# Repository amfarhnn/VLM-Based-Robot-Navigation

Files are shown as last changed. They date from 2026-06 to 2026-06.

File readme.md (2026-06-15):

<p align="center">
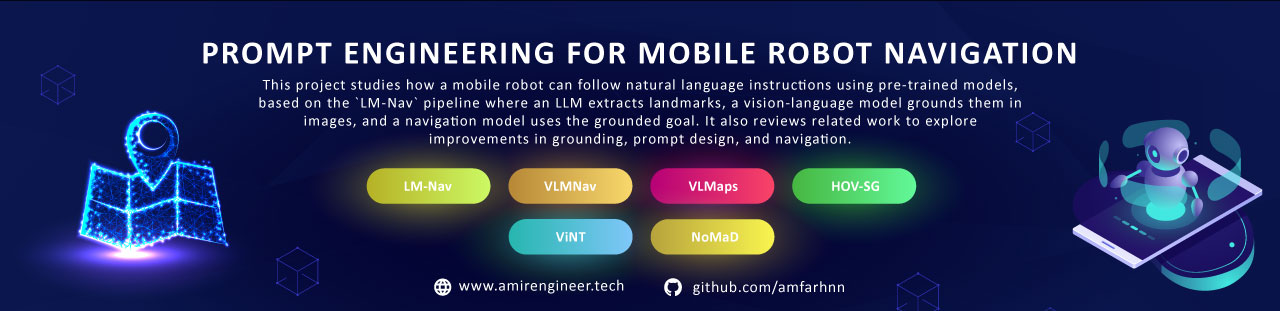
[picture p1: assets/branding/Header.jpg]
Prompt Engineering for Mobile Robot Navigation
  
</p>

# Prompt Engineering for Mobile Robot Navigation

<p align="center">
  A low-cost Raspberry Pi 4 and ESP32 mobile robot that converts a simple
  natural-language goal into restricted, safety-checked movement actions.
</p>

<p align="center">
  
  
  
  
  
</p>

## Final Thesis

The final FYP1 thesis, covering Chapters 1 to 5, is available here:

- [2115617_2_AmirFarhanGhaffar.pdf.docx](2115617_2_AmirFarhanGhaffar.pdf.docx)

The thesis is the source of truth for the finalized project scope, methodology,
AI-model research plan, Docker results, limitations, and planned FYP2 work.

## Prototype

<p align="center">
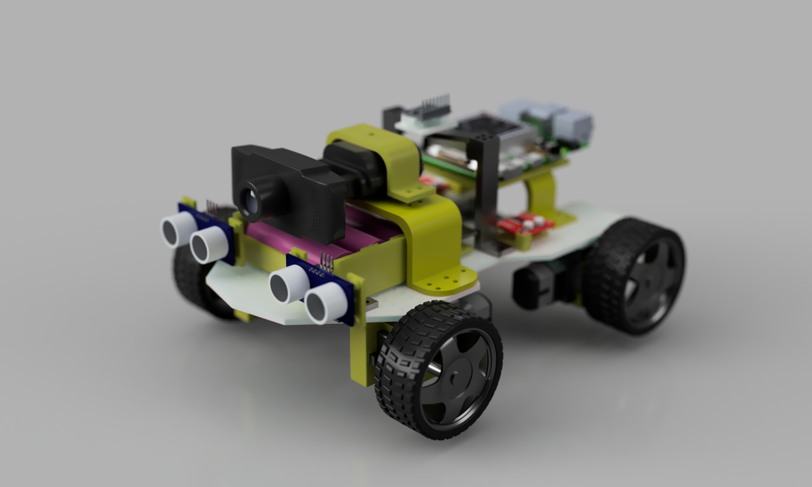
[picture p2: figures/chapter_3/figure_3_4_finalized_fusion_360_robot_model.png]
Finalized Fusion 360 Raspberry Pi robot model
  
</p>

The physical prototype uses:

- Raspberry Pi 4 for prompt processing, webcam perception, action selection,
  validation, and logging
- ESP32 for ultrasonic sensing, local safety, USB serial, and motor control
- USB webcam, two HC-SR04 sensors, and GY-291/ADXL345 accelerometer
- two MX1508 drivers and four DC gear motors
- protected 3S battery system, regulated power rails, main switch, and fuse

The GY-291/ADXL345 supports acceleration, roll/pitch, motion, vibration, and
shock observations. It does not provide yaw heading.

## Navigation Pipeline

```text
Natural-language instruction
        |
        v
Structured goal and approved action set
        |
        v
USB-webcam visual grounding
        |
        v
Restricted action selection
        |
        v
ESP32 safety validation and motor control
```

Approved actions:

```text
search | turn_left | turn_right | move_forward | stop
```

The ESP32 independently forces `STOP` for obstacles, sensor faults, invalid
commands, or a command timeout.

## Current Results

The completed Docker laptop demonstration accepts:

```text
find the door
```

It uses a fixed-schema prompt result and an OpenCV colour-and-shape detector
tuned to the grey-blue corridor doors used in the test area.

<p align="center">
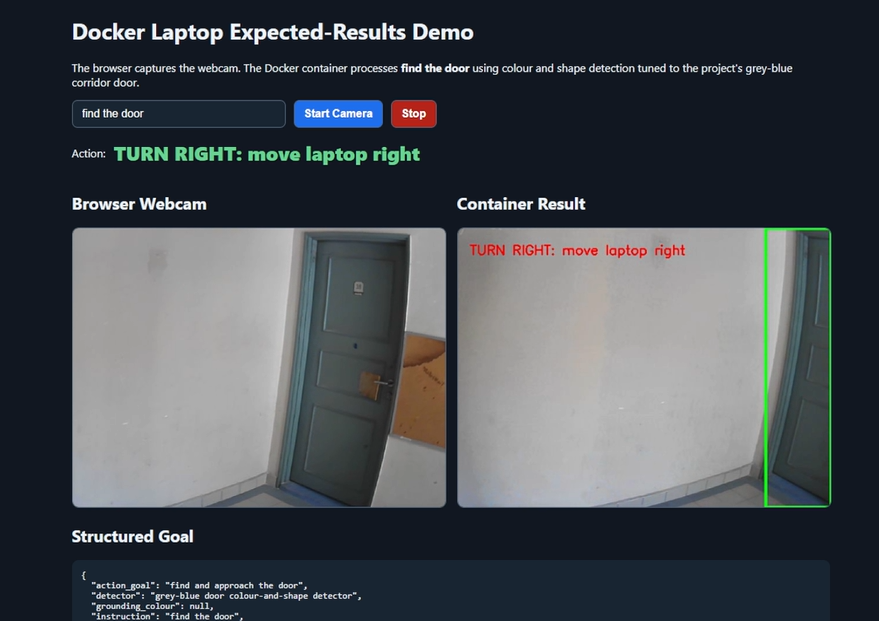
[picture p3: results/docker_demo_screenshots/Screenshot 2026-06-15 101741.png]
Docker demonstration selecting TURN RIGHT for a door on the right
  
</p>

Observed screenshot evidence demonstrates:

| Observed condition | Displayed action |
|---|---|
| No valid door region | `SEARCH` |
| Door detected on the right | `TURN RIGHT` |
| Door reaches the configured apparent-size threshold | `STOP` |

The Docker demonstration validates the high-level software interface. The
laptop was moved manually, and these results are not physical robot movement.

## AI Research Plan

The implemented deterministic parser, OpenCV detector, and rule-based action
selector form the measurable baseline. The thesis proposes three AI candidates
for later comparison:

| Candidate | Research role |
|---|---|
| Quantized TinyLlama | Convert instructions into the fixed navigation schema |
| MobileNetV2-SSD Lite TensorFlow Lite | Lightweight custom indoor-object grounding |
| VLM-NAV-inspired neural classifier | Compare learned and rule-based action selection |

Model output must pass deterministic validation and cannot bypass ESP32 safety.

## Project Status

| Area | Status |
|---|---|
| Final FYP1 thesis, Chapters 1-5 | Complete |
| Fusion 360 design and printable mounts | Complete |
| Mechanical chassis and protected power system | Built |
| Docker `find the door` demonstration | Working |
| Raspberry Pi controller and ESP32 firmware | Implemented |
| Final Raspberry Pi, ESP32, sensor, and motor wiring | In progress |
| Raised-wheel and controlled-floor validation | Planned for FYP2 |
| AI-model comparison and physical navigation measurements | Planned for FYP2 |

## Quick Start: Docker Demo

Requirements:

- Docker Desktop using Linux containers
- browser webcam permission
- local port `8000`

Run from the repository root:

```powershell
docker compose -f docker-compose.laptop-demo.yml up --build
```

Open <http://localhost:8000>, select **Start Camera**, and enter
`find the door`.

Stop the demonstration:

```powershell
docker compose -f docker-compose.laptop-demo.yml down
```

Full instructions:
[Docker Laptop Demonstration Setup](docs/laptop_only_expected_results_setup.md)

## Physical Robot Setup

1. Complete the signal wiring using the
   [Raspberry Pi, ESP32, and MX1508 Wiring Guide](docs/circuit_wiring_guide.md).
2. Flash
   [`firmware/esp32_robot_controller/esp32_robot_controller.ino`](firmware/esp32_robot_controller/esp32_robot_controller.ino).
3. Install Raspberry Pi OS and dependencies using the
   [Raspberry Pi 4 Full Software Setup](docs/raspberry_pi_4_full_software_setup.md).
4. Run the Raspberry Pi controller without `--execute` for the first dry test.
5. Enable movement only during supervised raised-wheel testing.

Example dry run:

```bash
python3 src/raspberry_pi_robot/robot_controller.py \
  --instruction "find the green marker" \
  --camera 0 \
  --serial-device /dev/ttyUSB0
```

The controller always sends `STOP` unless `--execute` is explicitly provided.

## Safety

- Never power motors from Raspberry Pi or ESP32 logic pins.
- Level-shift both 5 V HC-SR04 Echo signals before ESP32 GPIO.
- Keep a common ground between the battery system, power modules, ESP32,
  sensors, and motor drivers.
- Begin motor tests with all wheels raised and the main switch reachable.
- Verify `STOP`, obstacle, sensor-fault, invalid-command, and timeout behaviour
  before any controlled-floor test.

## Repository Structure

| Path | Purpose |
|---|---|
| [`2115617_2_AmirFarhanGhaffar.pdf.docx`](2115617_2_AmirFarhanGhaffar.pdf.docx) | Final FYP1 thesis, Chapters 1-5 |
| [`src/raspberry_pi_robot/`](src/raspberry_pi_robot/) | Raspberry Pi prompt, camera, action, serial, and logging controller |
| [`src/laptop_expected_results/`](src/laptop_expected_results/) | Docker browser-webcam demonstration |
| [`firmware/`](firmware/) | Main ESP32 controller and sensor-only test firmware |
| [`docs/`](docs/) | Wiring, setup, method-selection, and presentation guides |
| [`results/docker_demo_screenshots/`](results/docker_demo_screenshots/) | Captured Docker result screenshots |
| [`simulations/`](simulations/) | Assumption-based obstacle and timeout safety simulations |
| [`figures/`](figures/) | Final report and public-view figures |
| [`drawio/`](drawio/) | Editable and exported report diagrams |
| [`cad/design_sources/`](cad/design_sources/) | Fusion 360 renders, drawing, and design source |
| [`cad/stl/`](cad/stl/) | Printable robot mounts |
| [`assets/`](assets/) | README branding and hardware-component image sources |
| [`scripts/`](scripts/) | Reproducible figure-generation utilities |
| [`github-research-papers/`](github-research-papers/) | Related research implementations used for method study |

## Supporting Documentation

- [FYP1 15-Minute Presentation Script](docs/fyp1_15_minute_presentation_script.md)
- [Research-Paper Method Selection](docs/research_paper_method_selection.md)
- [Docker Laptop Demonstration Setup](docs/laptop_only_expected_results_setup.md)
- [Raspberry Pi 4 Full Software Setup](docs/raspberry_pi_4_full_software_setup.md)
- [Circuit Wiring Guide](docs/circuit_wiring_guide.md)

## Limitations

- The Docker detector is tuned to grey-blue doors in one corridor and is not a
  general semantic door-recognition model.
- Door stopping uses apparent image area, not measured physical distance.
- Two ultrasonic sensors provide limited obstacle coverage.
- The first physical baseline uses coloured-marker grounding.
- Complete physical action validation and AI-model comparison remain FYP2 work.

## Author

**Amir Farhan Bin Ghaffar**<br>
Final Year Project, Department of Mechatronics Engineering<br>
International Islamic University Malaysia

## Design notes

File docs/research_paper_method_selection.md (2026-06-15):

# Research-Paper Method Selection for the Raspberry Pi Robot

## 1. Purpose

This document evaluates the repositories in `github-research-papers` against
the finalized project hardware:

- Raspberry Pi 4 with one USB RGB webcam
- ESP32 with two front HC-SR04 ultrasonic sensors
- GY-291 / ADXL345 accelerometer
- two MX1508 motor drivers and four DC gear motors
- USB serial communication between Raspberry Pi and ESP32

The current robot has no RGB-D camera, wheel encoders, reliable yaw sensor,
LiDAR, GPS, SLAM pose, ROS installation, or GPU accelerator. Therefore, the
best approach is to adapt selected research methods rather than attempt to run
one complete research repository.

## 2. Recommended Combined Method

The most suitable design combines ideas from four repositories:

1. **LM-Nav:** convert a language instruction into an ordered list of
   landmarks or targets.
2. **VLM-NAV:** use a small discrete action space and fuse perception,
   obstacle sensing, and previous-action information.
3. **NaVid / NaVILA:** use recent visual history and separate high-level
   decisions from the real-time safety controller.
4. **ViNT:** optionally add a simple taught-route image sequence in future
   work.

The resulting project-specific pipeline is:

```text
Natural-language instruction
        |
        v
Constrained landmark and goal extraction
        |
        v
Recent webcam frames + marker or object grounding
        |
        v
Rule-based or lightweight learned action selector
        |
        v
Restricted action: search / left / right / forward / stop
        |
        v
ESP32 obstacle, sensor-fault, invalid-command, and timeout safety
        |
        v
MX1508 motor drivers and four motors
```

## 3. Compatibility Summary

| Repository | Suitable Part | Suitability | Main Limitation |
|---|---|---:|---|
| `lm_nav` | Ordered landmark extraction and modular pipeline | High | Full graph routing requires localization and visual embeddings |
| `vlm_nav` | Discrete actions, sensor fusion, previous-action memory, tiny action network | High with adaptation | Original method assumes depth maps, heading, AirSim, and optional API VLM |
| `NaVILA` | Two-level high-level decision and low-level safety concept | High as an architecture principle | Full VLA model requires powerful GPU hardware |
| `NaVid-VLN-CE` | Recent-frame history and constrained action parsing | Medium as a lightweight adaptation | Full video VLM requires GPU and simulator stack |
| `visualnav-transformer` | Taught-route image keyframes and waypoint-control concept | Medium for future work | Full ViNT/NoMaD deployment expects ROS, odometry, and stronger compute |
| `vlmaps` | Language-indexed map and spatial instruction ideas | Low for current hardware | Requires RGB-D frames and reliable camera or robot poses |
| `HOV-SG` | Floor-room-object hierarchy for future prompt design | Low for current hardware | Requires posed RGB-D, large models, point clouds, and substantial RAM/GPU |

## 4. Methods Suitable for the Current Prototype

### 4.1 LM-Nav Ordered Landmark Extraction

LM-Nav separates instruction interpretation from visual navigation. Its
landmark-extraction stage converts a full instruction into an ordered landmark
list.

Relevant local files:

- `github-research-papers/lm_nav/lm_nav/landmark_extraction.py`
- `github-research-papers/lm_nav/lm_nav/pipeline.py`

This method fits the project title and can extend the current fixed-schema
parser without requiring a large onboard model.

Example:

```text
Instruction: Find the green marker, then find the blue marker.

Structured goal:
{
  "ordered_targets": ["green marker", "blue marker"],
  "current_target_index": 0,
  "allowed_actions": ["search", "turn_left", "turn_right", "move_forward", "stop"]
}
```

For the first prototype, keep one supported target. Ordered multi-target
navigation should only be enabled after single-target trials are reliable.

### 4.2 VLM-NAV Discrete Action and Sensor-Fusion Method

VLM-NAV uses three discrete movement actions and combines perception with
left/right distance sensing, previous action, and rule-based decisions.

Relevant local files:

- `github-research-papers/vlm_nav/vlm_nav/vlm_navigation.py`
- `github-research-papers/vlm_nav/vlm_nav/navigator.py`
- `github-research-papers/vlm_nav/vlm_nav/navigation_learner.py`

The current project already uses a compatible restricted action set. The
method can be adapted using available robot observations:

| Research Input | Project Adaptation |
|---|---|
| Depth-map regions | Marker or object visibility, centre position, and area |
| Left/right distance sensors | Front-left and front-right HC-SR04 distance |
| Relative heading | Not available; do not claim yaw from the ADXL345 |
| Previous action | Store the previous selected action |
| Three movement actions | Use left, right, and forward plus safe search and stop |

Previous-action memory is useful for reducing rapid left-right oscillation.
However, the research code sometimes resolves an opposite turn by forcing
forward movement. The physical robot must instead keep the safer turn or stop;
it must never move forward only to suppress oscillation.

### 4.3 Tiny Learned Action Selector

The VLM-NAV `Navigator` is a small fully connected network. A similarly small
classifier can run on Raspberry Pi CPU after enough robot-specific data has
been collected.

Recommended future input features:

```text
target_visible
target_center_x
target_area_ratio
front_left_cm
front_right_cm
obstacle
sensor_fault
previous_action
roll_deg
pitch_deg
motion_detected
```

Recommended output classes:

```text
search, turn_left, turn_right, move_forward, stop
```

The rule-based controller should remain the FYP1 baseline. In FYP2, manually
label safe actions, train the small model on a laptop, deploy inference on the
Raspberry Pi, and compare it against the baseline. The ESP32 safety layer must
override either method.

### 4.4 NaVILA Two-Level Control Architecture

NaVILA separates high-level language-based decisions from real-time locomotion
and obstacle avoidance.

Relevant local reference:

- `github-research-papers/NaVILA/README.md`

This principle already matches the project:

| NaVILA Concept | Project Implementation |
|---|---|
| High-level navigation command | Raspberry Pi prompt, vision, and action selection |
| Real-time locomotion and avoidance | ESP32 motor control and deterministic safety |

Use this architecture as research justification. Do not attempt to run the
full NaVILA model on Raspberry Pi 4.

### 4.5 NaVid Recent-Frame History

NaVid uses historical observations and the current image when selecting the
next action.

Relevant local files:

- `github-research-papers/NaVid-VLN-CE/agent_navid.py`
- `github-research-papers/NaVILA/llava/eval/run_navigation.py`

A lightweight version is suitable for Raspberry Pi:

1. Keep the last three to five marker detections, not full VLM features.
2. Use median target centre and area across valid detections.
3. Require repeated evidence before changing turn direction.
4. Stop if the visual history is inconsistent or sensor status is unavailable.

Do not copy NaVid's random-action fallback when model output is invalid. An
invalid decision on the physical robot must produce `stop`.

## 5. Methods Suitable Only for Later Work

### 5.1 ViNT Taught-Route Image Sequence

ViNT creates a topological map from images sampled along a demonstrated route.
The idea can become a future "teach and repeat" mode:

1. Manually drive the robot through a short indoor route.
2. Store ordered webcam keyframes.
3. Match the current image against nearby keyframes.
4. Move toward the next keyframe while ESP32 safety remains active.

For the current hardware, begin with lightweight ORB image matching rather
than the full ViNT/NoMaD neural model. Reliable metric waypoint control would
require wheel encoders and a real heading sensor.

Relevant local files:

- `github-research-papers/visualnav-transformer/deployment/src/create_topomap.py`
- `github-research-papers/visualnav-transformer/deployment/src/pd_controller.py`

### 5.2 VLMaps Spatial Language Ideas

VLMaps demonstrates object-goal and relation-aware instructions such as moving
beside or between objects. These ideas are useful for future prompt schemas,
but its actual mapping pipeline is not compatible with the present robot.

The full method requires RGB-D observations and reliable world-frame poses.
The current USB RGB webcam, ultrasonic sensors, and ADXL345 cannot provide
those inputs.

### 5.3 HOV-SG Hierarchical Scene Representation

The floor-room-object hierarchy is useful as a future language representation:

```text
floor -> room -> object -> action
```

The full HOV-SG implementation is unsuitable for Raspberry Pi 4 because it
uses posed RGB-D data, point clouds, OpenCLIP, SAM, and substantial RAM/GPU
resources.

## 6. Methods Not Recommended for This Setup

Do not use the following as the first physical implementation:

- full NaVILA, NaVid, or Uni-NaVid inference on Raspberry Pi 4
- full VLMaps or HOV-SG map construction
- full ViNT/NoMaD deployment without ROS, odometry, and stronger compute
- monocular estimated depth as the only collision-safety source
- ADXL345 roll or pitch as robot yaw or compass heading
- random movement when parsing, perception, or model output fails
- unrestricted VLM output sent directly to the ESP32

An API-based VLM can be tested as an optional comparison, but network latency,
availability, cost, and unpredictable text output make it unsuitable as the
only physical control method.

## 7. Recommended Implementation Roadmap

### FYP1: Current Basic Prototype

1. Keep the fixed-schema parser and one target: `find the green marker`.
2. Keep OpenCV marker grounding and the restricted five-action set.
3. Add previous-action logging and lightweight temporal detection history.
4. Keep all obstacle and communication safety on the ESP32.
5. Measure prompt validity, grounding correctness, action correctness,
   latency, safe-stop rate, and goal completion.

### FYP2: First Research Extension

1. Extend the parser to ordered supported landmarks.
2. Collect robot-specific observation and safe-action examples.
3. Train a tiny action classifier and compare it with the rule-based baseline.
4. Replace markers with lightweight indoor-object detection.
5. Add a short taught-route image sequence if time permits.

### Hardware Needed Before Map-Based Navigation

- wheel encoders for distance and odometry
- a gyroscope or magnetometer-capable IMU for turning or heading feedback
- preferably an RGB-D camera or LiDAR for map construction
- stronger compute or offboard GPU for large VLM, VLMaps, HOV-SG, or ViNT

## 8. Final Selection

The recommended method for this project is:

> A modular LM-Nav-inspired prompt and landmark pipeline, using a VLM-NAV-style
> restricted action selector with lightweight temporal history, while the
> Raspberry Pi performs high-level decisions and the ESP32 independently
> enforces real-time safety.

This selection is technically realistic for Raspberry Pi 4, directly supports
the project title, and leaves a clear comparison path between rule-based and
small learned action selection for FYP2.

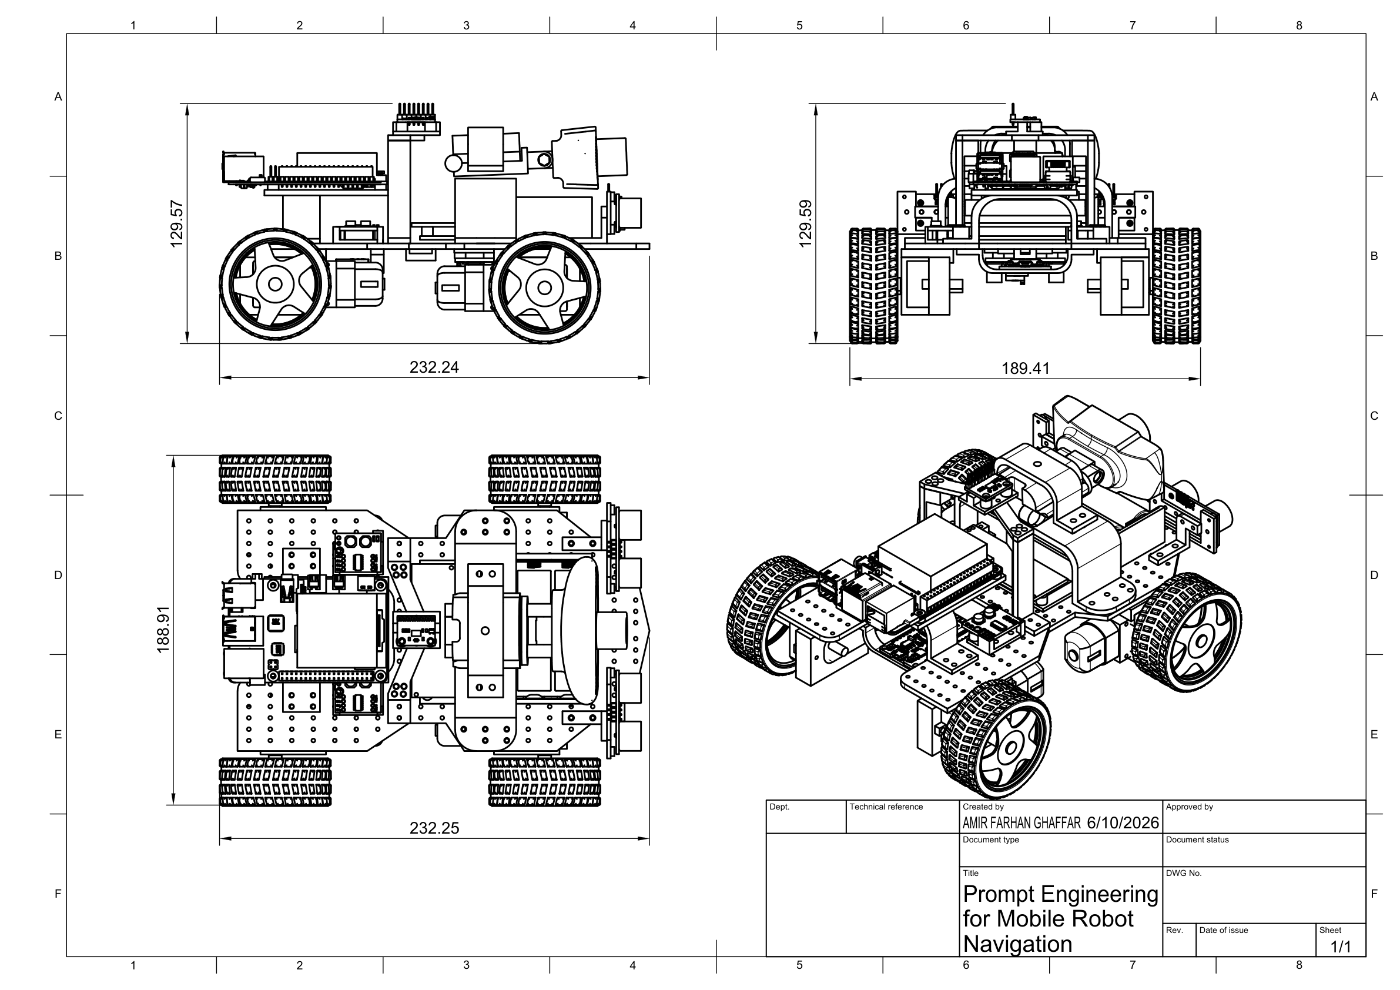
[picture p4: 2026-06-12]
figures/chapter_3/figure_3_6_mechanical_design_sketch_and_dimensions.png

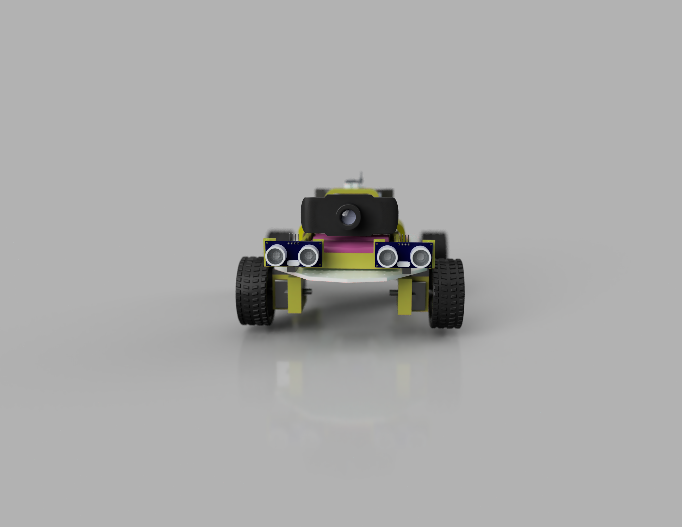
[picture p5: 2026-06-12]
cad/design_sources/FYP_2_2026-Jun-10_09-45-14PM-000_CustomizedView45560590010.png

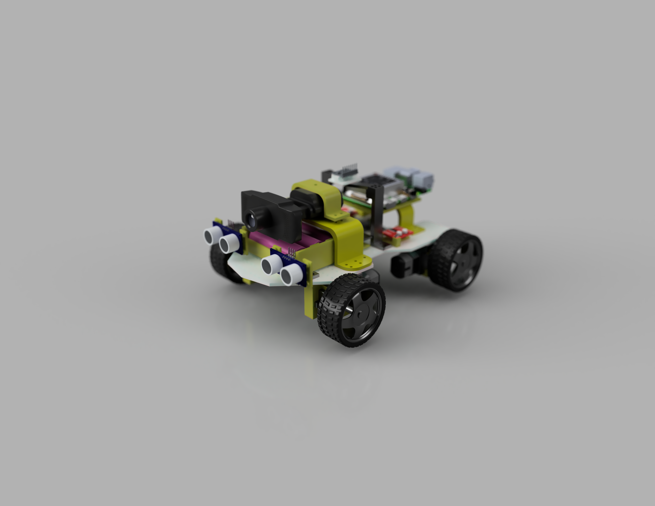
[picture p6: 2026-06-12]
cad/design_sources/FYP_2_2026-Jun-10_09-44-41PM-000_CustomizedView7494680794.png

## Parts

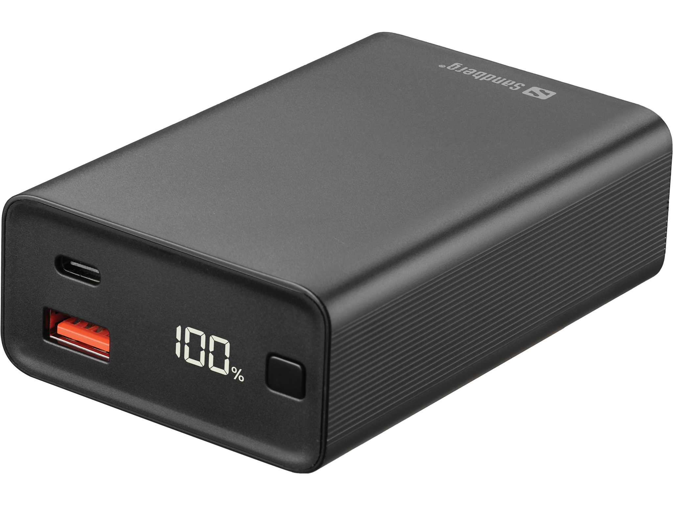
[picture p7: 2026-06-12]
assets/hardware_components/powerbank_battery.jpg

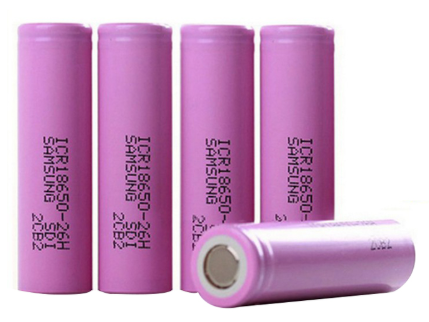
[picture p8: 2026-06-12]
assets/hardware_components/18650_battery.png

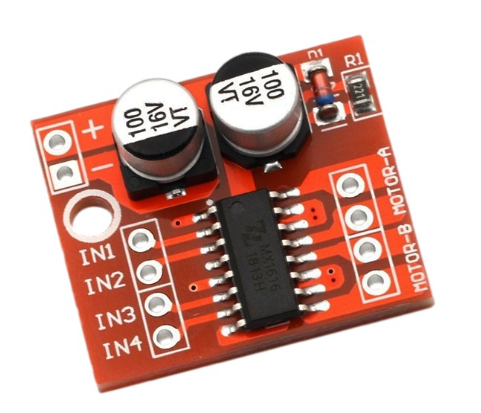
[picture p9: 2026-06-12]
assets/hardware_components/mx1508_motor_driver.png

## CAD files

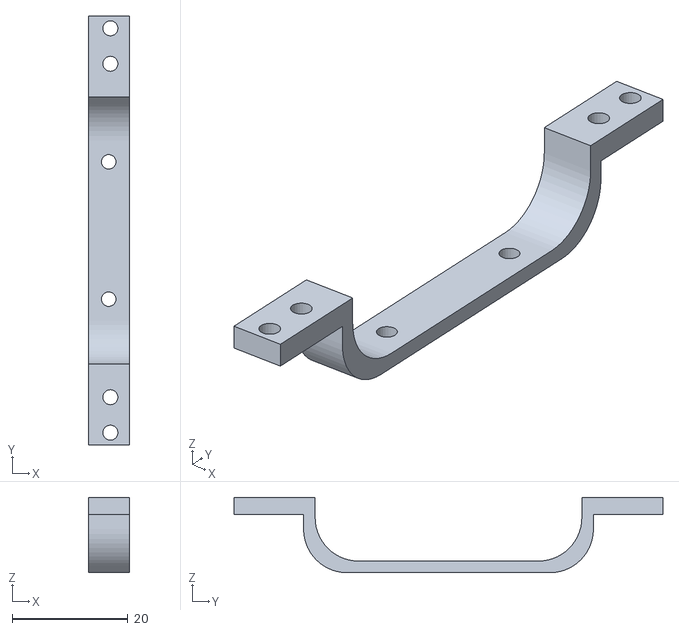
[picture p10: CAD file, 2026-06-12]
cad/stl/2Mount esp32.stl
7.00 x 74.0 x 13.0

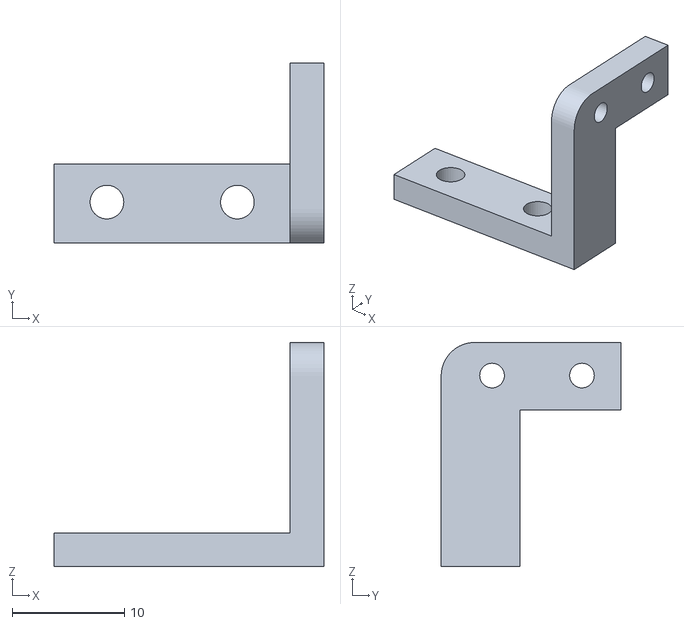
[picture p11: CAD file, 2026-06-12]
cad/stl/left Ultrasonic mount base.stl
24.0 x 16.0 x 20.0

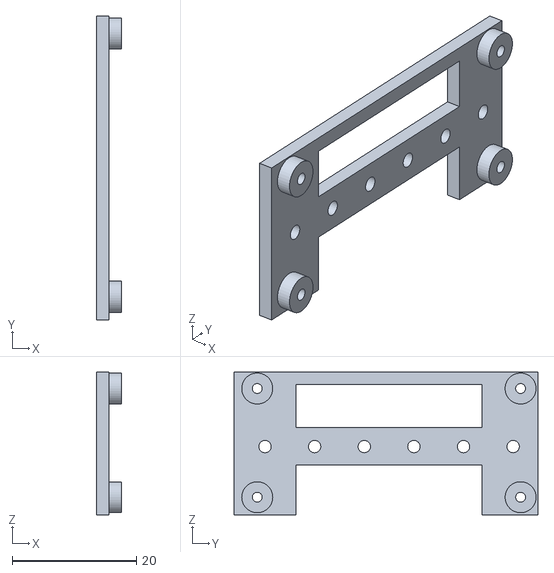
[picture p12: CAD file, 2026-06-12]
cad/stl/left Ultrasonics Mounting.stl
4.00 x 49.0 x 23.0

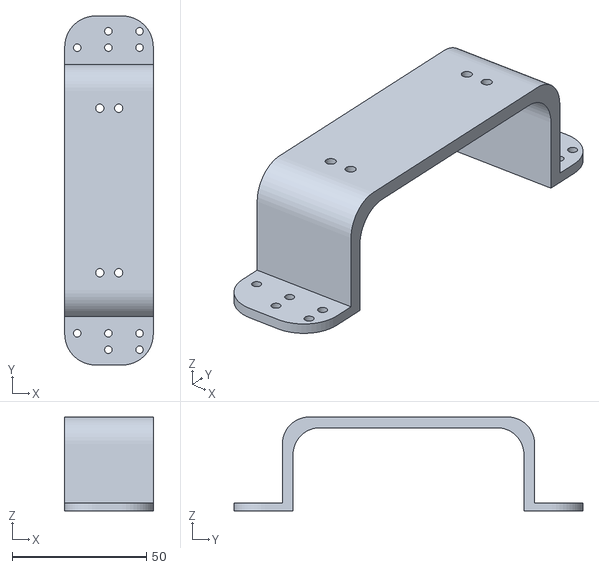
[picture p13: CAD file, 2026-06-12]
cad/stl/Stand Webcam.stl
33.0 x 130.0 x 35.0

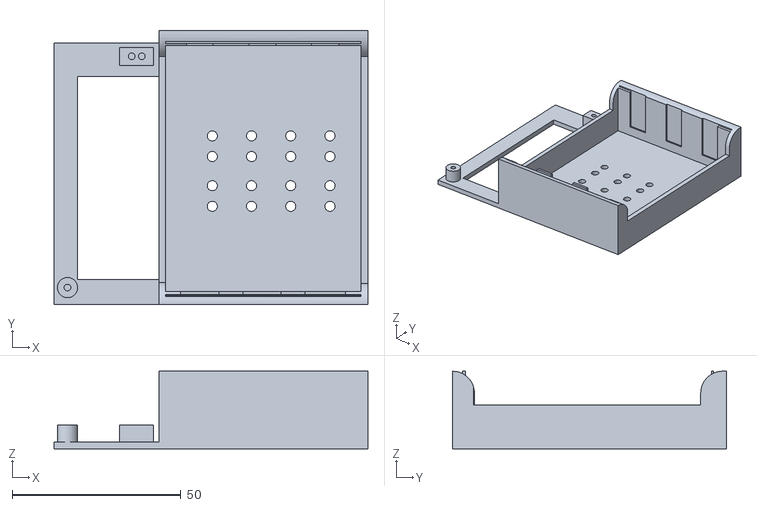
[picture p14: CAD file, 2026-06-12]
cad/stl/Battery Mount System.stl
93.0 x 81.1 x 23.0

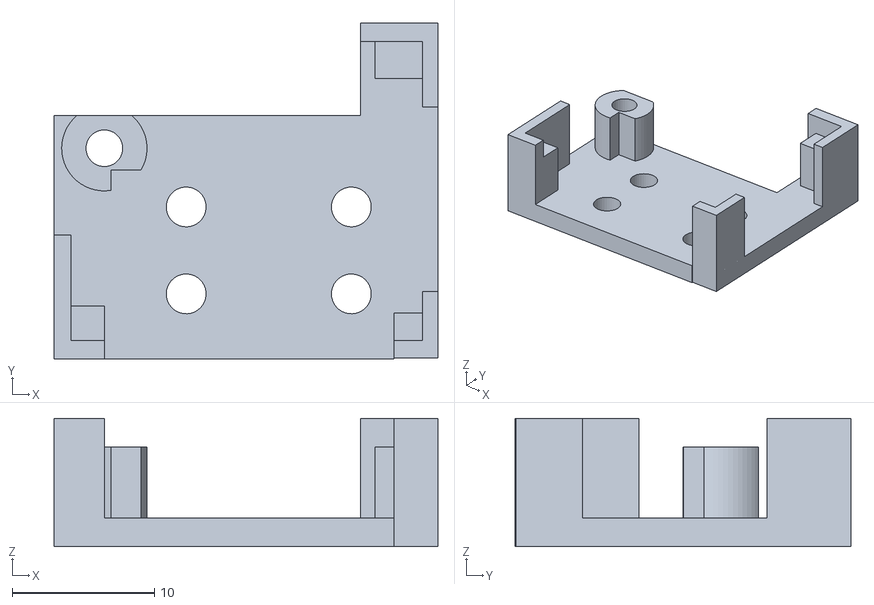
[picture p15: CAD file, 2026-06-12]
cad/stl/Driver motor mount.stl
27.0 x 23.6 x 9.00

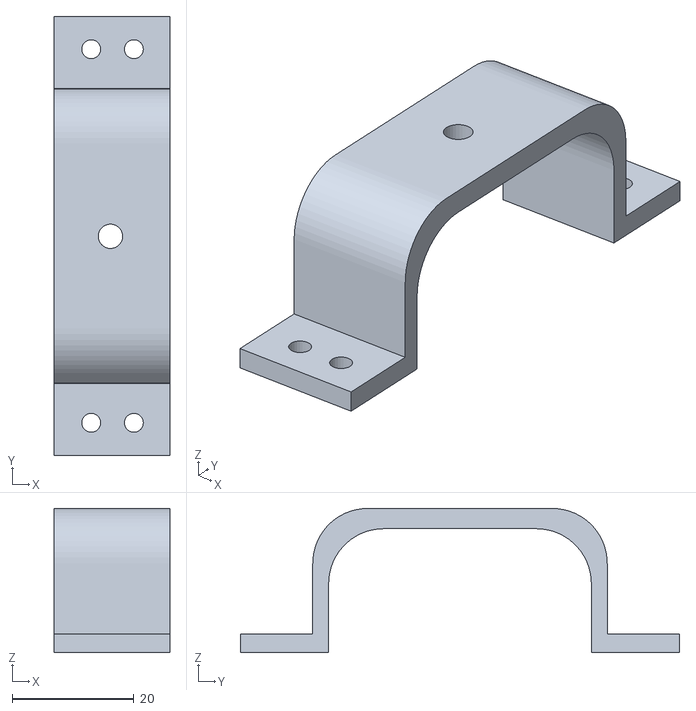
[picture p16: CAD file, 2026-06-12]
cad/stl/Webcam Fitting.stl
19.0 x 72.0 x 23.6

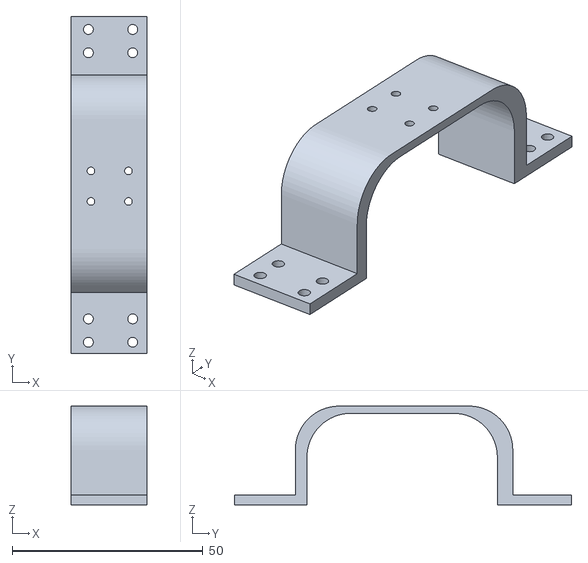
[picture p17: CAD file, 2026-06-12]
cad/stl/stand pi4 tall.stl
20.0 x 88.3 x 25.9

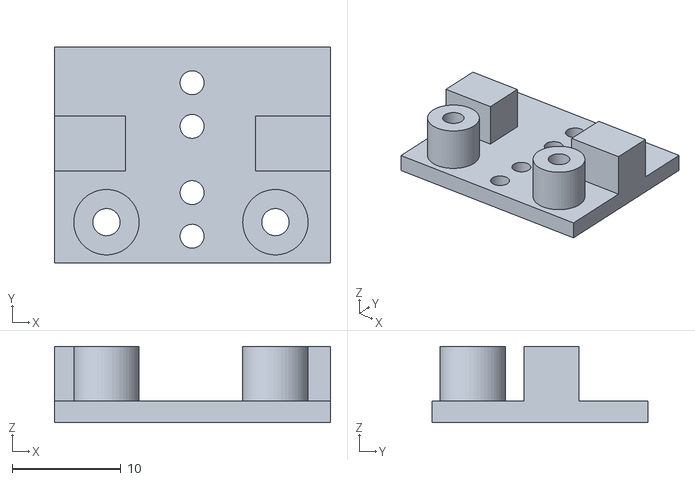
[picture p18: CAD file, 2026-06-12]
cad/stl/IMU mount.stl
25.3 x 19.8 x 7.00

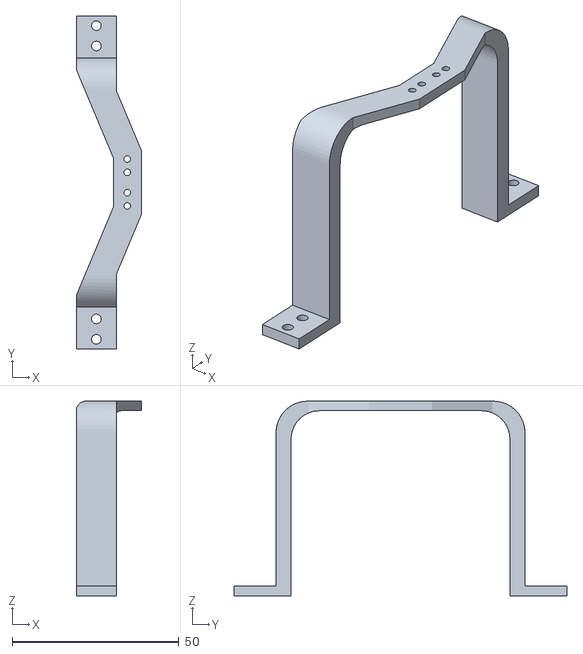
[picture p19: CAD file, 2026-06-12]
cad/stl/IMU Stand.stl
19.6 x 100.0 x 58.5

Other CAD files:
cad/stl/right Ultrasonic mount base.stl
cad/stl/right Ultrasonics Mounting.stl

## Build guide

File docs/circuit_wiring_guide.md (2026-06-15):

# Raspberry Pi 4, ESP32, and MX1508 Wiring Guide

This guide covers the remaining signal wiring for the finalized Raspberry Pi 4
physical prototype. The power system is assumed to be already assembled and
verified. Do not connect power until every signal connection has been checked.

## 1. Final Signal Architecture

```text
USB webcam --------------------------> Raspberry Pi 4 USB port
ESP32 USB data + power cable <------> Raspberry Pi 4 USB port
                                            |
                                            v
                                           ESP32
                                            |
                     +----------------------+----------------------+
                     |                      |                      |
              two HC-SR04             GY-291 / ADXL345       two MX1508
                                                                  |
                                                          four DC motors
```

USB serial is the finalized Raspberry Pi-to-ESP32 interface. It provides
communication and makes the ESP32 easy to flash and debug without consuming
Raspberry Pi or ESP32 UART GPIO pins.

## 2. Safety Before Wiring

- Switch off and disconnect the battery.
- Verify the motor and logic/compute rail voltages with a multimeter.
- Power the Raspberry Pi through a stable regulated USB-C supply.
- For the first prototype, power the ESP32 only from the Raspberry Pi USB data + power
  cable. Do not simultaneously connect a separate ESP32 5 V supply.
- Never connect motor power to Raspberry Pi or ESP32 logic pins.
- HC-SR04 Echo is normally 5 V and must be level-shifted before ESP32 GPIO.
- Keep a common ground between ESP32, both MX1508 drivers, sensors, and the
  power-system ground.
- Begin motor testing with all wheels raised.

## 3. Raspberry Pi 4 to ESP32

Connect an ESP32 USB data + power cable to any Raspberry Pi USB port.

| Raspberry Pi Connection | ESP32 Connection | Purpose |
|---|---|---|
| USB port | ESP32 USB port | Commands, sensor JSON, flashing, and debugging |

The ESP32 normally appears as `/dev/ttyUSB0` or `/dev/ttyACM0`.

Do not also connect direct UART wires during the first prototype. USB serial is
the only Raspberry Pi-to-ESP32 control connection required.

The normal USB cable also powers the ESP32. If the final robot must power the
ESP32 from a separate regulated supply, use a verified data-only USB cable or a
USB power blocker so the Raspberry Pi and external 5 V outputs are not joined.

## 4. ESP32 Final Pin Assignment

| Function | ESP32 Pin |
|---|---:|
| Front-left HC-SR04 Trigger | GPIO 5 |
| Front-left HC-SR04 Echo through level shifting | GPIO 34 |
| Front-right HC-SR04 Trigger | GPIO 18 |
| Front-right HC-SR04 Echo through level shifting | GPIO 35 |
| GY-291 SDA | GPIO 21 |
| GY-291 SCL | GPIO 22 |
| Front-left motor inputs | GPIO 25 and GPIO 26 |
| Front-right motor inputs | GPIO 27 and GPIO 14 |
| Rear-left motor inputs | GPIO 32 and GPIO 33 |
| Rear-right motor inputs | GPIO 16 and GPIO 17 |

GPIO 16 and GPIO 17 return to the rear-right motor channel because Raspberry
Pi communication uses USB serial.

## 5. ESP32 to Two MX1508 Drivers

| Driver | Channel | Motor | ESP32 Inputs |
|---|---|---|---|
| MX1508 Driver 1 | Channel A | Front-left | GPIO 25 and GPIO 26 |
| MX1508 Driver 1 | Channel B | Rear-left | GPIO 32 and GPIO 33 |
| MX1508 Driver 2 | Channel A | Front-right | GPIO 27 and GPIO 14 |
| MX1508 Driver 2 | Channel B | Rear-right | GPIO 16 and GPIO 17 |

For each MX1508:

| MX1508 Connection | Connect To |
|---|---|
| Motor-supply positive | Verified motor buck-converter positive output |
| Motor-supply ground | Motor buck-converter ground and common ground |
| Channel input pins | Assigned ESP32 GPIO pins |
| Channel output terminals | Corresponding DC motor |

Do not power motors from the ESP32 or Raspberry Pi. Confirm motor stall current
remains within the MX1508 module rating.

## 6. ESP32 to HC-SR04 Sensors

| Sensor | Pin | Connection |
|---|---|---|
| Front-left HC-SR04 | VCC | Verified 5 V sensor supply |
| Front-left HC-SR04 | GND | Common ground |
| Front-left HC-SR04 | Trigger | ESP32 GPIO 5 |
| Front-left HC-SR04 | Echo | Level shifter or resistor divider, then GPIO 34 |
| Front-right HC-SR04 | VCC | Verified 5 V sensor supply |
| Front-right HC-SR04 | GND | Common ground |
| Front-right HC-SR04 | Trigger | ESP32 GPIO 18 |
| Front-right HC-SR04 | Echo | Level shifter or resistor divider, then GPIO 35 |

Example Echo resistor divider:

```text
HC-SR04 Echo ---- 1 kOhm ----+---- ESP32 Echo GPIO
                             |
                           2 kOhm
                             |
                            GND
```

## 7. ESP32 to GY-291 / ADXL345

| GY-291 Pin | Connection |
|---|---|
| VCC | Supply voltage supported by the exact module |
| GND | Common ground |
| SDA | ESP32 GPIO 21 |
| SCL | ESP32 GPIO 22 |

The GY-291 supports acceleration, roll/pitch estimation, motion, vibration, and
shock observations. It does not provide yaw or compass heading.

## 8. Recommended Wiring Order

1. Disconnect battery power.
2. Connect all common-ground wires.
3. Connect GY-291 I2C signals.
4. Connect HC-SR04 Trigger and level-shifted Echo signals.
5. Connect ESP32 control signals to both MX1508 drivers.
6. Connect each motor to its assigned MX1508 output channel.
7. Recheck continuity and verify there is no short between supply and ground.
8. Power only the logic rail.
9. Confirm no separate ESP32 5 V supply is connected, then connect the ESP32
   and webcam to Raspberry Pi USB ports.
10. Test Raspberry Pi-to-ESP32 USB serial.
11. Power the motor rail with wheels raised and test one action at a time.

## 9. Raspberry Pi-to-ESP32 Communication Test

```bash
python3 -m serial.tools.list_ports -v
python3 - <<'PY'
import serial, time
port = serial.Serial('/dev/ttyUSB0', 115200, timeout=1)
port.write(b'PING\n')
time.sleep(0.2)
for _ in range(5):
    print(port.readline().decode(errors='ignore').strip())
port.write(b'STOP\n')
port.close()
PY
```

Change `/dev/ttyUSB0` if the ESP32 appears as another device.

## 10. Motor Direction Test

Keep wheels raised:

```bash
python3 - <<'PY'
import serial, time
port = serial.Serial('/dev/ttyUSB0', 115200, timeout=1)
for command in ('FWD', 'STOP', 'LEFT', 'STOP', 'RIGHT', 'STOP'):
    print('sending', command)
    port.write((command + '\n').encode())
    time.sleep(0.5)
port.write(b'STOP\n')
port.close()
PY
```

If one wheel rotates in the wrong direction, switch off power and reverse only
that motor's two output wires.

## 11. Final Checklist

- [ ] Raspberry Pi uses a stable regulated USB-C supply.
- [ ] ESP32 uses only Raspberry Pi USB power, or the USB 5 V wire is safely
      isolated before separate ESP32 power is used.
- [ ] Webcam and ESP32 are connected to separate Raspberry Pi USB ports.
- [ ] ESP32 USB serial appears as `/dev/ttyUSB0` or `/dev/ttyACM0`.
- [ ] HC-SR04 Echo signals are level-shifted.
- [ ] Rear-right motor control uses ESP32 GPIO 16 and GPIO 17.
- [ ] All MX1508 grounds share the control-system ground.
- [ ] Motor power does not enter Raspberry Pi or ESP32 logic pins.
- [ ] Wheels are raised during the first movement test.
- [ ] `STOP` works before any floor test.

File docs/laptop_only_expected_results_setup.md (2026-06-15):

# Docker Laptop-Only Expected-Results Setup

This setup is a separate FYP1 feasibility and expected-results demonstration.
It is **not** another physical robot implementation and does not change the
finalized Raspberry Pi 4 hardware purpose.

The browser captures the laptop webcam and sends frames to a local Docker
container. The container performs the Python/OpenCV processing and returns
`TURN LEFT`, `TURN RIGHT`, `MOVE FORWARD`, `SEARCH`, or `STOP`. The user
manually moves the laptop according to the displayed instruction.

```text
Laptop webcam -> browser -> Docker Python/OpenCV service
                         -> structured goal and displayed action
                         -> JSONL result log
```

This design is used because Docker Desktop on Windows does not reliably expose
the laptop webcam as a Linux `/dev/video` device. Browser camera capture works
cleanly while the processing environment remains isolated and reproducible.

## Purpose

Use this option before the physical robot is ready to demonstrate:

- structured interpretation of a simple goal
- live webcam perception
- restricted action selection
- expected action changes when the target moves in the image
- repeatable containerized software setup
- result logging for Chapter 4 expected-results discussion

## First Demo Goal

Use the grey-blue corridor door shown in the selected project test area:

```text
find the door
```

The structured output identifies the target as `door`. OpenCV detects this
specific door using its grey-blue colour, tall rectangular shape, area, and
vertical position. The detector is intentionally tuned to this test door and
must not be presented as a general door-recognition model. This lightweight
method is easy to reproduce and does not require downloading a large model.

If corridor lighting changes significantly, tune `DOOR_HSV_LOWER` and
`DOOR_HSV_UPPER` in
`src/laptop_expected_results/laptop_navigation_demo.py`. Keep the door visible
from top to bottom during the first tests so its vertical shape can be checked.

## Requirements

- Windows 10 or Windows 11 laptop
- Docker Desktop using Linux containers
- Working browser webcam permission
- Available local port `8000`

Confirm Docker is running:

```powershell
docker --version
docker compose version
```

## Build and Run

From the project root:

```powershell
docker compose -f docker-compose.laptop-demo.yml up --build
```

Open:

```text
http://localhost:8000
```

Select **Start Camera** and allow browser camera access, then point and manually
move the laptop toward the grey-blue test door.

The container health endpoint is:

```text
http://localhost:8000/health
```

## Stop the Demo

Press `Ctrl+C` in the Docker terminal, then run:

```powershell
docker compose -f docker-compose.laptop-demo.yml down
```

To rebuild after changing Python or web-interface code:

```powershell
docker compose -f docker-compose.laptop-demo.yml build --no-cache
docker compose -f docker-compose.laptop-demo.yml up
```

## Expected Displayed Actions

| Webcam Result | Displayed Instruction | Manual User Action |
|---|---|---|
| Door not detected | `SEARCH` | Rotate or move the laptop slowly |
| Door appears on left | `TURN LEFT` | Move the laptop view left |
| Door appears on right | `TURN RIGHT` | Move the laptop view right |
| Door is centred | `MOVE FORWARD` | Carry the laptop toward the door |
| Door fills a large image area | `STOP` | Stop moving |

## Docker Files

| File | Purpose |
|---|---|
| `docker-compose.laptop-demo.yml` | Builds, starts, and maps the service to port 8000 |
| `src/laptop_expected_results/Dockerfile` | Defines the Python container |
| `src/laptop_expected_results/requirements.txt` | Pins Flask, OpenCV, NumPy, and Gunicorn |
| `src/laptop_expected_results/web_app.py` | Processes browser webcam frames |
| `src/laptop_expected_results/templates/index.html` | Browser webcam and result interface |
| `src/laptop_expected_results/laptop_navigation_demo.py` | Shared structured-goal and action logic |

## Expected-Results Evidence

The host project receives the container log through a bind mount:

```text
logs/laptop_expected_results.jsonl
```

For FYP1, record:

- screenshots showing each displayed action
- ten or more repeated runs
- whether the displayed action matches the target position
- action-change response time
- the Docker image/build version used
- failure cases caused by lighting, similar colours, or partial target view

## Troubleshooting

### Browser does not show the webcam

- Open `http://localhost:8000`, not a remote IP address.
- Allow camera permission in the browser.
- Close applications that exclusively use the webcam.
- Reload the page and select **Start Camera** again.

### Port 8000 is already in use

Change the host side of the port mapping:

```yaml
ports:
  - "8080:8000"
```

Then open `http://localhost:8080`.

### Container fails to start

```powershell
docker compose -f docker-compose.laptop-demo.yml logs
docker compose -f docker-compose.laptop-demo.yml ps
```

This evidence supports the expected result that the planned restricted action
interface behaves logically. Final FYP2 claims must use the physical Raspberry
Pi 4 robot and measured robot results.

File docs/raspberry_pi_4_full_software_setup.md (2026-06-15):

# Raspberry Pi 4 Full Software Setup

This is the only finalized physical implementation for the project. The first
prototype accepts `find the green marker`, uses the USB webcam to locate the
marker, selects a restricted action, and sends the action to the ESP32 through
USB serial. The ESP32 controls the motors and independently stops for
obstacles, sensor faults, invalid commands, or command timeout.

```text
instruction -> structured goal -> webcam marker detection -> safe action
            -> Raspberry Pi USB serial -> ESP32 -> MX1508 -> robot movement
```

## 1. First-Prototype Decision

The first physical result uses a large coloured marker because it is reliable,
measurable, and does not require downloading or converting a large model.

- Prompt engineering uses a deterministic fixed-schema parser.
- Visual grounding uses OpenCV colour-marker detection.
- Supported first targets are `green marker`, `blue marker`, and
  `yellow marker`.
- The action set is `search`, `turn_left`, `turn_right`, `move_forward`, and
  `stop`.
- The ESP32 retains final authority over physical safety.

After this baseline works, OpenCV DNN, TensorFlow Lite, an API-based VLM, or a
custom landmark detector can replace the colour detector without changing the
ESP32 motor and safety layer.

## 2. Required Hardware

- Raspberry Pi 4 with microSD card
- Stable regulated Raspberry Pi supply, preferably 5.1 V / 3 A through USB-C
- ESP32 connected to the Raspberry Pi using a USB data + power cable
- USB UVC-compatible webcam connected to another Raspberry Pi USB port
- Two MX1508 motor drivers and four DC gear motors
- Two HC-SR04 sensors with level-shifted Echo signals
- GY-291 / ADXL345
- Completed protected power system, fuse, and main switch

Do not power motors from the Raspberry Pi. Keep the wheels raised until the
supervised movement test.

For the first prototype, allow the Raspberry Pi USB cable to power the ESP32
and do not connect a second ESP32 5 V source. If separate ESP32 power is later
required, use a verified data-only USB cable or USB power blocker.

## 3. Install Raspberry Pi OS

Use Raspberry Pi Imager on the development computer:

1. Select **Raspberry Pi 4**.
2. Select **Raspberry Pi OS Lite (64-bit)** for a headless robot.
3. Select the microSD card.
4. In OS customisation, configure:
   - hostname, for example `vlm-robot`
   - username and strong password
   - Wi-Fi and locale
   - SSH enabled
5. Write the image and boot the Raspberry Pi.

Connect from the development computer:

```bash
ssh <username>@vlm-robot.local
```

Official references:

- <https://www.raspberrypi.com/documentation/computers/getting-started.html>
- <https://www.raspberrypi.com/documentation/remote-access/>

## 4. Update the Raspberry Pi

```bash
sudo apt update
sudo apt full-upgrade -y
sudo reboot
```

Reconnect after reboot and confirm the 64-bit architecture:

```bash
uname -m
```

Expected result:

```text
aarch64
```

## 5. Install Required Software

```bash
sudo apt install -y \
  git \
  python3-venv \
  python3-opencv \
  python3-numpy \
  python3-serial \
  v4l-utils
```

Clone or copy this repository:

```bash
cd ~
git clone <your-repository-url> vlm-robot
cd ~/vlm-robot
python3 -m venv --system-site-packages .venv
source .venv/bin/activate
python3 -c "import cv2, numpy, serial; print('imports okay')"
```

The `--system-site-packages` option allows the virtual environment to use the
OpenCV and NumPy packages installed by Raspberry Pi OS.

## 6. Confirm the USB Webcam

Connect the webcam and list video devices:

```bash
v4l2-ctl --list-devices
ls -l /dev/video*
```

Test camera index `0`:

```bash
source ~/vlm-robot/.venv/bin/activate
python3 - <<'PY'
import cv2
camera = cv2.VideoCapture(0)
ok, frame = camera.read()
print("capture_ok=", ok, "shape=", None if frame is None else frame.shape)
camera.release()
PY
```

If capture fails, try camera index `1`.

## 7. Flash and Connect the ESP32

Flash:

```text
firmware/esp32_robot_controller/esp32_robot_controller.ino
```

Connect the ESP32 USB port to the Raspberry Pi using a USB data + power cable.
Find the serial device:

```bash
python3 -m serial.tools.list_ports -v
ls -l /dev/ttyUSB* /dev/ttyACM* 2>/dev/null
```

Add the Raspberry Pi user to the serial-access group:

```bash
sudo usermod -aG dialout "$USER"
sudo reboot
```

The ESP32 usually appears as `/dev/ttyUSB0` or `/dev/ttyACM0`.

## 8. Test Raspberry Pi-to-ESP32 Communication

```bash
source ~/vlm-robot/.venv/bin/activate
python3 - <<'PY'
import serial, time
port = serial.Serial('/dev/ttyUSB0', 115200, timeout=1)
port.write(b'PING\n')
time.sleep(0.2)
for _ in range(5):
    print(port.readline().decode(errors='ignore').strip())
port.write(b'STOP\n')
port.close()
PY
```

Change `/dev/ttyUSB0` to the detected device if required.

Expected response includes:

```json
{"status":"ok","device":"esp32_robot_controller"}
```

Sensor JSON should also arrive repeatedly.

## 9. Run the First Dry Test

Place a large green marker in the test area. Dry-run mode processes the prompt,
camera, and sensor input but always sends `STOP`:

```bash
cd ~/vlm-robot
source .venv/bin/activate
python3 src/raspberry_pi_robot/robot_controller.py \
  --instruction "find the green marker" \
  --camera 0 \
  --serial-device /dev/ttyUSB0
```

Confirm the output and `logs/raspberry_pi_navigation.jsonl` contain:

- structured target `green marker`
- marker detection or safe `search`
- ESP32 sensor JSON
- selected action and reason
- end-to-end latency
- `sent_command: STOP` while dry-run mode is active

## 10. Run the First Physical Result

Keep wheels raised and the main switch within reach:

```bash
python3 src/raspberry_pi_robot/robot_controller.py \
  --instruction "find the green marker" \
  --camera 0 \
  --serial-device /dev/ttyUSB0 \
  --execute
```

Stop with `Ctrl+C`. The controller sends `STOP` during shutdown.

Expected behaviour:

| Camera and Sensor Condition | Expected Action |
|---|---|
| Unsupported or unclear instruction | `STOP` |
| Marker is not detected | `SEARCH` |
| Marker is on the left | `LEFT` |
| Marker is on the right | `RIGHT` |
| Marker is centred and not close | `FWD` |
| Marker reaches the configured goal size | `STOP` |
| Ultrasonic obstacle or sensor fault | ESP32 forces `STOP` |
| Raspberry Pi commands stop for more than 1 second | ESP32 forces `STOP` |

## 11. Optional Docker Engine on Raspberry Pi

Docker is optional for the physical Raspberry Pi prototype. Native execution is
recommended first because it makes USB webcam and ESP32 debugging easier.

Use Raspberry Pi OS 64-bit. Docker Engine officially supports the Debian arm64
architecture used by Raspberry Pi OS 64-bit:

<https://docs.docker.com/engine/install/debian/>

After the native physical loop is reliable, the controller may be
containerized with explicit device mappings such as:

```text
--device=/dev/video0
--device=/dev/ttyUSB0
```

## 12. Final Development Path

1. Demonstrate repeatable `find the green marker` behaviour.
2. Record prompt validity, grounding correctness, action correctness, latency,
   safe-stop rate, and movement success.
3. Calibrate motor direction, speed, ultrasonic threshold, and marker-size stop
   threshold.
4. Replace colour-marker grounding with a lightweight object detector.
5. Add targets such as chair, door, and signboard.
6. Add relation-aware prompts only after single-target movement is reliable.
7. Keep the ESP32 safety layer independent from all high-level decisions.

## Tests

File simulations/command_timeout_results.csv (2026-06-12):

elapsed_ms | expected_motor_state
0 | COMMANDED_MOTION_AVAILABLE
100 | COMMANDED_MOTION_AVAILABLE
200 | COMMANDED_MOTION_AVAILABLE
300 | COMMANDED_MOTION_AVAILABLE
400 | COMMANDED_MOTION_AVAILABLE
500 | COMMANDED_MOTION_AVAILABLE
600 | COMMANDED_MOTION_AVAILABLE
700 | COMMANDED_MOTION_AVAILABLE
800 | COMMANDED_MOTION_AVAILABLE
900 | COMMANDED_MOTION_AVAILABLE
1000 | COMMANDED_MOTION_AVAILABLE
1100 | STOP
1200 | STOP
1300 | STOP
1400 | STOP
1500 | STOP
1600 | STOP

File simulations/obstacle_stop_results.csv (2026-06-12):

front_left_cm | front_right_cm | expected_response
0 | 0 | STOP
5 | 5 | STOP
10 | 10 | STOP
15 | 15 | STOP
20 | 20 | STOP
25 | 25 | MOVEMENT_MAY_BE_PERMITTED
30 | 30 | MOVEMENT_MAY_BE_PERMITTED
35 | 35 | MOVEMENT_MAY_BE_PERMITTED
40 | 40 | MOVEMENT_MAY_BE_PERMITTED
45 | 45 | MOVEMENT_MAY_BE_PERMITTED
50 | 50 | MOVEMENT_MAY_BE_PERMITTED
55 | 55 | MOVEMENT_MAY_BE_PERMITTED
60 | 60 | MOVEMENT_MAY_BE_PERMITTED

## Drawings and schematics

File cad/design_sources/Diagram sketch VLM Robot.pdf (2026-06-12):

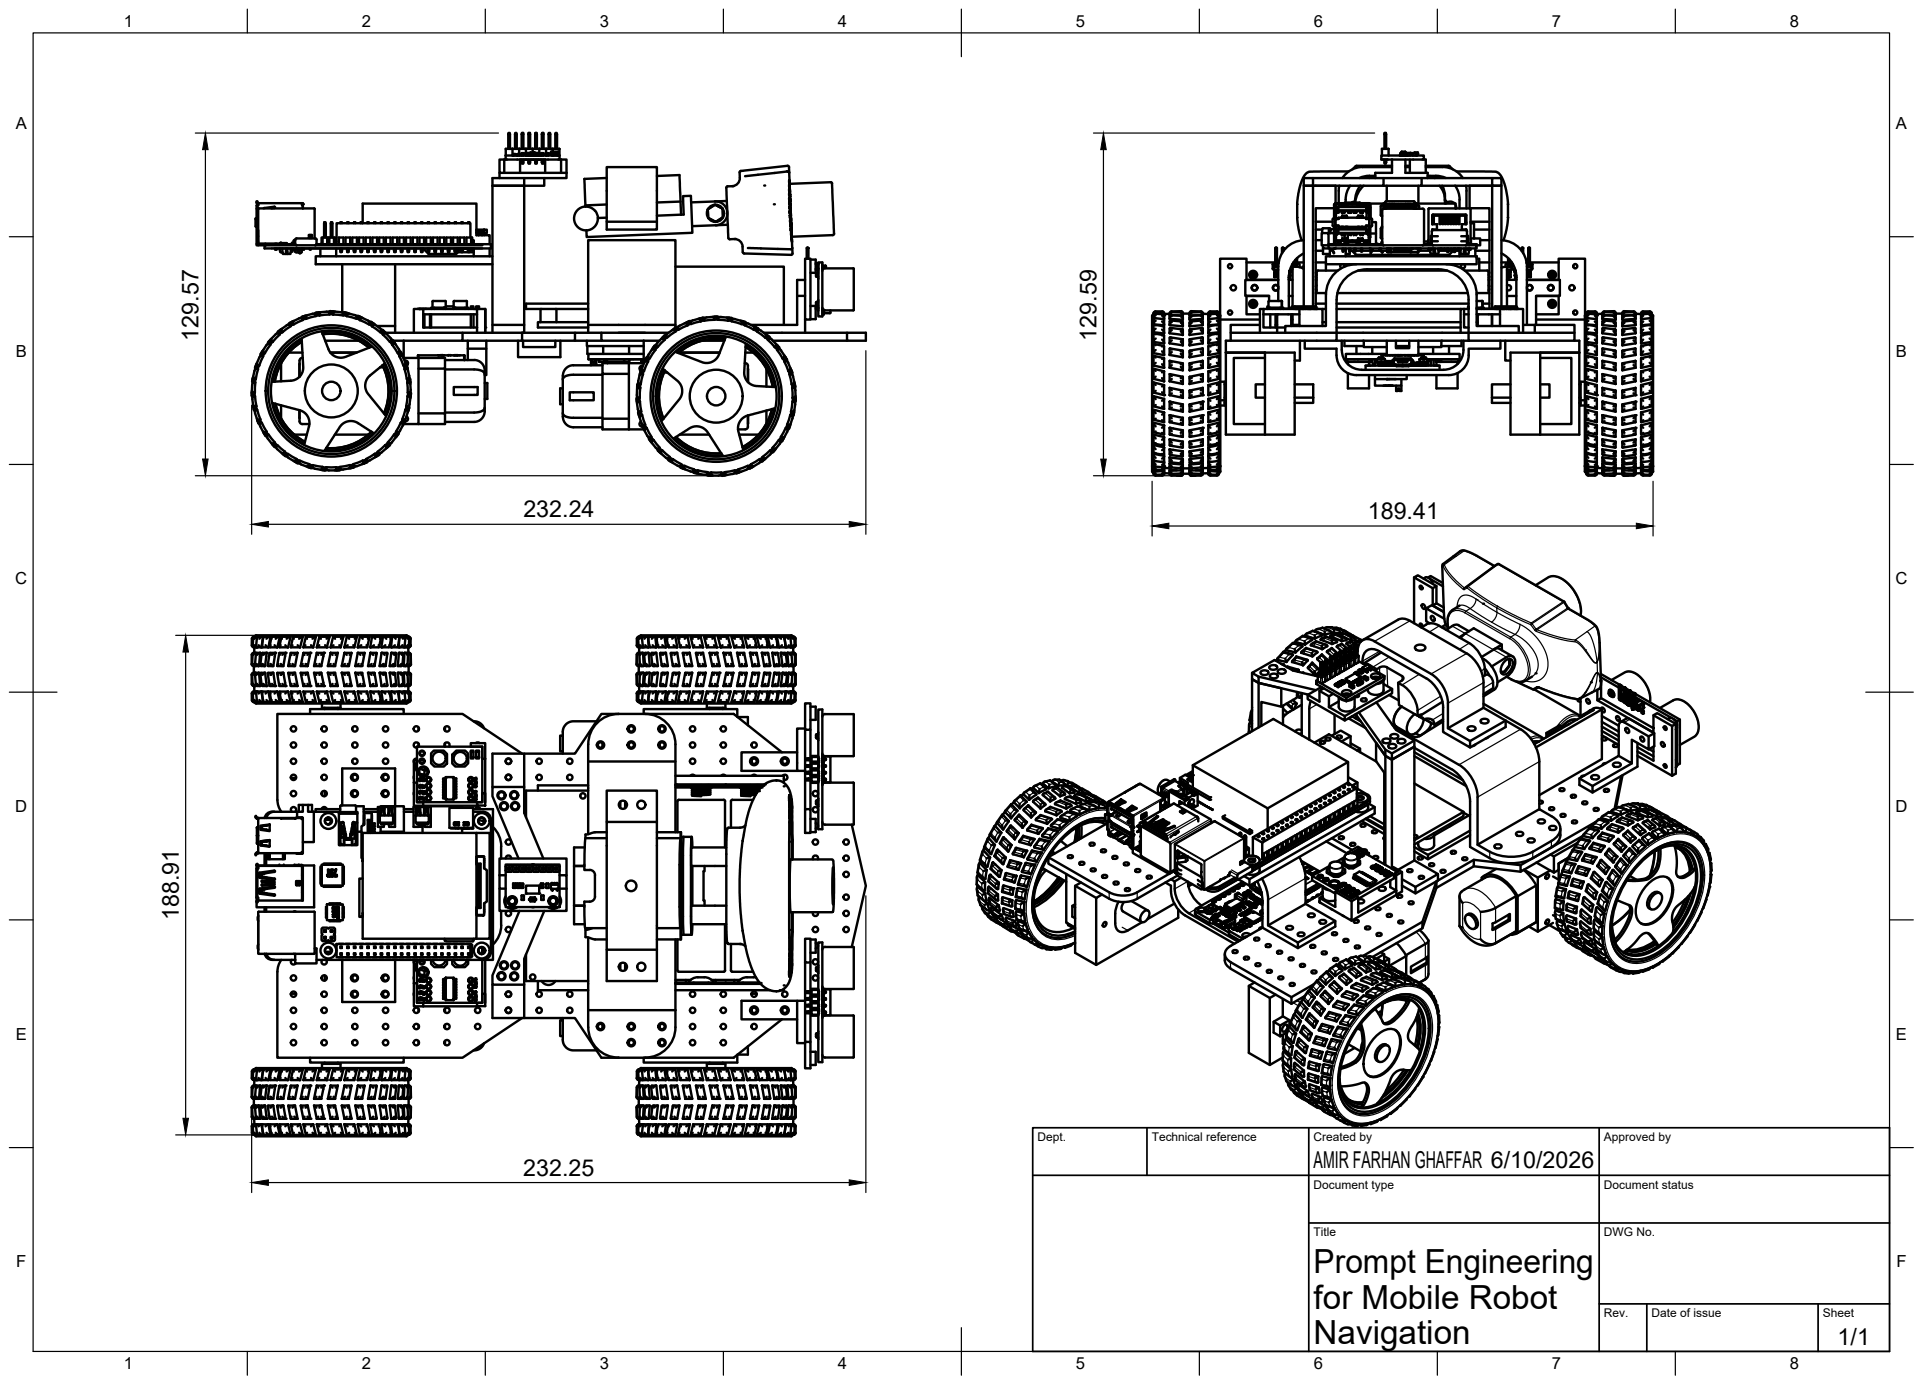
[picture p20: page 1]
Dept.; Technical reference; Created by; Approved by; Document type; Document status; Title; DWG No.; Rev.; Date of issue; Sheet

AMIR FARHAN GHAFFAR

Prompt Engineering
for Mobile Robot
Navigation

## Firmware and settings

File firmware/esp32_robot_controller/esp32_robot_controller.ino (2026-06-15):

/*
  ESP32 robot controller for the Raspberry Pi 4 FYP prototype.

  ESP32 responsibilities:
  - Read two front HC-SR04 ultrasonic sensors.
  - Read a GY-291 / ADXL345 accelerometer over I2C.
  - Publish JSON sensor status to the Raspberry Pi 4 over USB serial.
  - Receive high-level movement commands.
  - Control four DC motors through two MX1508 dual H-bridge modules.
  - Stop on obstacle, unknown command, or command timeout.

  Hardware notes:
  - Use level shifting on each 5 V HC-SR04 Echo signal.
  - GY-291 / ADXL345 provides acceleration, roll/pitch tilt, and
    motion/vibration/shock observations.
  - MX1508 channels use two PWM-capable inputs per motor.
  - For the first prototype, the ESP32 USB port provides power, serial
    communication, and development access from the Raspberry Pi.
  - Confirm all pins and electrical ratings before physical testing.
*/

#include <Wire.h>

const unsigned long BAUD_RATE = 115200;
const unsigned long MEASURE_INTERVAL_MS = 100;
const unsigned long COMMAND_TIMEOUT_MS = 1000;
const unsigned long PULSE_TIMEOUT_US = 30000;

const int BASE_SPEED = 90;
const int TURN_SPEED = 80;
const int SEARCH_SPEED = 65;

const int SENSOR_COUNT = 2;
const char* SENSOR_NAMES[SENSOR_COUNT] = {"front_left", "front_right"};
const int TRIG_PINS[SENSOR_COUNT] = {5, 18};
const int ECHO_PINS[SENSOR_COUNT] = {34, 35};

const int I2C_SDA_PIN = 21;
const int I2C_SCL_PIN = 22;
const uint8_t ADXL345_ADDRESS = 0x53;
const float MOTION_THRESHOLD_G = 0.08;
const float VIBRATION_DELTA_THRESHOLD_G = 0.05;
const float SHOCK_THRESHOLD_G = 1.50;

struct MotorPins {
  int input1;
  int input2;
};

// Two MX1508 modules provide four two-input motor channels.
MotorPins frontLeft  = {25, 26};
MotorPins frontRight = {27, 14};
MotorPins rearLeft   = {32, 33};
MotorPins rearRight  = {16, 17};

float safeDistanceCm = 25.0;
float latestDistances[SENSOR_COUNT] = {-1.0, -1.0};
float latestMinCm = -1.0;
bool latestObstacle = false;
bool latestSensorFault = true;

bool adxl345Available = false;
float accelXG = 0.0;
float accelYG = 0.0;
float accelZG = 0.0;
float accelMagnitudeG = 0.0;
float previousAccelMagnitudeG = 1.0;
float rollDeg = 0.0;
float pitchDeg = 0.0;
bool motionDetected = false;
bool vibrationDetected = false;
bool shockDetected = false;

unsigned long lastMeasureMs = 0;
unsigned long lastCommandMs = 0;

void setup() {
  Serial.begin(BAUD_RATE);

  for (int i = 0; i < SENSOR_COUNT; i++) {
    pinMode(TRIG_PINS[i], OUTPUT);
    pinMode(ECHO_PINS[i], INPUT);
    digitalWrite(TRIG_PINS[i], LOW);
  }

  setupMotor(frontLeft);
  setupMotor(frontRight);
  setupMotor(rearLeft);
  setupMotor(rearRight);
  stopAll();

  Wire.begin(I2C_SDA_PIN, I2C_SCL_PIN);
  adxl345Available = setupAdxl345();
  lastCommandMs = millis();
}

void loop() {
  handleSerialCommand();

  unsigned long now = millis();
  if (now - lastMeasureMs >= MEASURE_INTERVAL_MS) {
    lastMeasureMs = now;
    updateSensors();
    publishSensorStatus();
  }

  if (latestObstacle || latestSensorFault || (now - lastCommandMs > COMMAND_TIMEOUT_MS)) {
    stopAll();
  }
}

void handleSerialCommand() {
  if (!Serial.available()) {
    return;
  }

  String command = Serial.readStringUntil('\n');
  command.trim();
  command.toUpperCase();

  if (command == "PING") {
    Serial.println("{\"status\":\"ok\",\"device\":\"esp32_robot_controller\"}");
    return;
  }

  if (command.startsWith("THRESHOLD=")) {
    float value = command.substring(10).toFloat();
    if (value > 0.0 && value < 500.0) {
      safeDistanceCm = value;
      Serial.print("{\"status\":\"threshold_updated\",\"safe_distance_cm\":");
      Serial.print(safeDistanceCm, 1);
      Serial.println("}");
    }
    return;
  }

  executeCommand(command);
  lastCommandMs = millis();
}

void executeCommand(String command) {
  if ((latestObstacle || latestSensorFault) && command != "STOP") {
    stopAll();
    Serial.println(latestObstacle ? "ACK:STOP:OBSTACLE" : "ACK:STOP:SENSOR_FAULT");
    return;
  }

  if (command == "FWD") {
    moveForward(BASE_SPEED);
    Serial.println("ACK:FWD");
  } else if (command == "LEFT") {
    turnLeft(TURN_SPEED);
    Serial.println("ACK:LEFT");
  } else if (command == "RIGHT") {
    turnRight(TURN_SPEED);
    Serial.println("ACK:RIGHT");
  } else if (command == "SEARCH") {
    turnLeft(SEARCH_SPEED);
    Serial.println("ACK:SEARCH");
  } else {
    stopAll();
    Serial.println("ACK:STOP");
  }
}

void updateSensors() {
  float minDistance = 9999.0;

  for (int i = 0; i < SENSOR_COUNT; i++) {
    latestDistances[i] = readDistanceCm(TRIG_PINS[i], ECHO_PINS[i]);
    if (latestDistances[i] > 0.0 && latestDistances[i] < minDistance) {
      minDistance = latestDistances[i];
    }
  }

  latestMinCm = minDistance >= 9999.0 ? -1.0 : minDistance;
  latestSensorFault = latestMinCm < 0.0;
  latestObstacle = latestMinCm > 0.0 && latestMinCm < safeDistanceCm;

  if (adxl345Available) {
    adxl345Available = readAdxl345();
  }
}

void publishSensorStatus() {
  Serial.print("{");
  for (int i = 0; i < SENSOR_COUNT; i++) {
    Serial.print("\"");
    Serial.print(SENSOR_NAMES[i]);
    Serial.print("_cm\":");
    if (latestDistances[i] < 0.0) {
      Serial.print("null");
    } else {
      Serial.print(latestDistances[i], 1);
    }
    Serial.print(",");
  }

  Serial.print("\"min_cm\":");
  if (latestMinCm < 0.0) {
    Serial.print("null");
  } else {
    Serial.print(latestMinCm, 1);
  }

  Serial.print(",\"obstacle\":");
  Serial.print(latestObstacle ? "true" : "false");
  Serial.print(",\"sensor_fault\":");
  Serial.print(latestSensorFault ? "true" : "false");
  Serial.print(",\"accel_g\":");
  if (!adxl345Available) {
    Serial.print("null");
  } else {
    Serial.print("{\"x\":");
    Serial.print(accelXG, 3);
    Serial.print(",\"y\":");
    Serial.print(accelYG, 3);
    Serial.print(",\"z\":");
    Serial.print(accelZG, 3);
    Serial.print("}");
  }
  Serial.print(",\"roll_deg\":");
  Serial.print(adxl345Available ? String(rollDeg, 1) : "null");
  Serial.print(",\"pitch_deg\":");
  Serial.print(adxl345Available ? String(pitchDeg, 1) : "null");
  Serial.print(",\"motion_detected\":");
  Serial.print(motionDetected ? "true" : "false");
  Serial.print(",\"vibration_detected\":");
  Serial.print(vibrationDetected ? "true" : "false");
  Serial.print(",\"shock_detected\":");
  Serial.print(shockDetected ? "true" : "false");
  Serial.println("}");
}

float readDistanceCm(int trigPin, int echoPin) {
  digitalWrite(trigPin, LOW);
  delayMicroseconds(2);
  digitalWrite(trigPin, HIGH);
  delayMicroseconds(10);
  digitalWrite(trigPin, LOW);

  unsigned long duration = pulseIn(echoPin, HIGH, PULSE_TIMEOUT_US);
  if (duration == 0) {
    return -1.0;
  }

  return duration / 58.0;
}

bool setupAdxl345() {
  Wire.beginTransmission(ADXL345_ADDRESS);
  Wire.write(0x2D);  // POWER_CTL
  Wire.write(0x08);  // Measurement mode
  if (Wire.endTransmission() != 0) {
    return false;
  }

  Wire.beginTransmission(ADXL345_ADDRESS);
  Wire.write(0x31);  // DATA_FORMAT
  Wire.write(0x08);  // Full resolution, +/-2 g
  return Wire.endTransmission() == 0;
}

bool readAdxl345() {
  Wire.beginTransmission(ADXL345_ADDRESS);
  Wire.write(0x32);  // DATAX0
  if (Wire.endTransmission(false) != 0) {
    return false;
  }

  if (Wire.requestFrom(ADXL345_ADDRESS, (uint8_t)6) != 6) {
    return false;
  }

  int16_t rawX = (int16_t)(Wire.read() | (Wire.read() << 8));
  int16_t rawY = (int16_t)(Wire.read() | (Wire.read() << 8));
  int16_t rawZ = (int16_t)(Wire.read() | (Wire.read() << 8));

  const float scaleGPerLsb = 0.0039;
  accelXG = rawX * scaleGPerLsb;
  accelYG = rawY * scaleGPerLsb;
  accelZG = rawZ * scaleGPerLsb;

  accelMagnitudeG = sqrt(
    accelXG * accelXG + accelYG * accelYG + accelZG * accelZG
  );
  rollDeg = atan2(accelYG, accelZG) * 180.0 / PI;
  pitchDeg = atan2(
    -accelXG,
    sqrt(accelYG * accelYG + accelZG * accelZG)
  ) * 180.0 / PI;

  motionDetected = abs(accelMagnitudeG - 1.0) > MOTION_THRESHOLD_G;
  vibrationDetected =
    abs(accelMagnitudeG - previousAccelMagnitudeG) >
    VIBRATION_DELTA_THRESHOLD_G;
  shockDetected = accelMagnitudeG > SHOCK_THRESHOLD_G;
  previousAccelMagnitudeG = accelMagnitudeG;
  return true;
}

void setupMotor(MotorPins motor) {
  pinMode(motor.input1, OUTPUT);
  pinMode(motor.input2, OUTPUT);
}

void moveForward(int speedValue) {
  setMotor(frontLeft, speedValue);
  setMotor(frontRight, speedValue);
  setMotor(rearLeft, speedValue);
  setMotor(rearRight, speedValue);
}

void turnLeft(int speedValue) {
  setMotor(frontLeft, -speedValue);
  setMotor(rearLeft, -speedValue);
  setMotor(frontRight, speedValue);
  setMotor(rearRight, speedValue);
}

void turnRight(int speedValue) {
  setMotor(frontLeft, speedValue);
  setMotor(rearLeft, speedValue);
  setMotor(frontRight, -speedValue);
  setMotor(rearRight, -speedValue);
}

void stopAll() {
  setMotor(frontLeft, 0);
  setMotor(frontRight, 0);
  setMotor(rearLeft, 0);
  setMotor(rearRight, 0);
}

void setMotor(MotorPins motor, int speedValue) {
  speedValue = constrain(speedValue, -255, 255);

  if (speedValue > 0) {
    analogWrite(motor.input1, speedValue);
    analogWrite(motor.input2, 0);
  } else if (speedValue < 0) {
    analogWrite(motor.input1, 0);
    analogWrite(motor.input2, -speedValue);
  } else {
    analogWrite(motor.input1, 0);
    analogWrite(motor.input2, 0);
  }
}

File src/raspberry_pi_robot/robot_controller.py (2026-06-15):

"""Basic Raspberry Pi 4 prompt-engineered robot navigation prototype.

The first physical milestone uses a large green, blue, or yellow marker as a
repeatable indoor landmark. The Raspberry Pi selects a restricted action while
the ESP32 remains responsible for obstacle, sensor-fault, and timeout safety.
"""

from __future__ import annotations

import argparse
import json
import time
from dataclasses import asdict, dataclass
from pathlib import Path
from typing import Any

import cv2
import numpy as np
import serial
from serial.tools import list_ports


ACTION_TO_COMMAND = {
    "move_forward": "FWD",
    "turn_left": "LEFT",
    "turn_right": "RIGHT",
    "search": "SEARCH",
    "stop": "STOP",
}

HSV_RANGES = {
    "green marker": ((35, 70, 50), (85, 255, 255)),
    "blue marker": ((90, 70, 50), (130, 255, 255)),
    "yellow marker": ((20, 80, 80), (35, 255, 255)),
}


@dataclass
class Goal:
    instruction: str
    target: str | None
    landmarks: list[str]
    spatial_relation: str | None
    action_goal: str
    uncertainty: str


@dataclass
class TargetDetection:
    label: str
    score: float
    center_x: float
    area_ratio: float


def parse_instruction(instruction: str) -> Goal:
    """Convert a simple instruction into the project's fixed prompt schema."""
    normalized = instruction.lower().strip()
    target = next((label for label in HSV_RANGES if label in normalized), None)
    if not target:
        return Goal(
            instruction=instruction,
            target=None,
            landmarks=[],
            spatial_relation=None,
            action_goal="stop because the target is unsupported or unclear",
            uncertainty="high",
        )
    return Goal(
        instruction=instruction,
        target=target,
        landmarks=[target],
        spatial_relation=None,
        action_goal=f"find and approach the {target}",
        uncertainty="low",
    )


def find_marker(frame: Any, target: str | None) -> TargetDetection | None:
    if target not in HSV_RANGES:
        return None
    lower, upper = HSV_RANGES[target]
    hsv = cv2.cvtColor(frame, cv2.COLOR_BGR2HSV)
    mask = cv2.inRange(hsv, np.array(lower), np.array(upper))
    mask = cv2.morphologyEx(mask, cv2.MORPH_OPEN, np.ones((5, 5), np.uint8))
    contours, _ = cv2.findContours(mask, cv2.RETR_EXTERNAL, cv2.CHAIN_APPROX_SIMPLE)
    if not contours:
        return None
    contour = max(contours, key=cv2.contourArea)
    area = float(cv2.contourArea(contour))
    frame_height, frame_width = frame.shape[:2]
    if area < 800:
        return None
    x, _, width, height = cv2.boundingRect(contour)
    return TargetDetection(
        label=target,
        score=min(1.0, area / (frame_width * frame_height * 0.15)),
        center_x=(x + width / 2) / frame_width,
        area_ratio=(width * height) / (frame_width * frame_height),
    )


def discover_esp32_device() -> str:
    candidates = [
        port.device
        for port in list_ports.comports()
        if any(name in (port.description or "").lower() for name in ("cp210", "ch340", "usb serial", "uart"))
    ]
    if len(candidates) == 1:
        return candidates[0]
    raise RuntimeError(
        "Unable to uniquely identify the ESP32 USB serial device. "
        "Run `python3 -m serial.tools.list_ports -v` and pass --serial-device."
    )


class Esp32Bridge:
    def __init__(self, device: str | None, baud: int) -> None:
        self.device = device or discover_esp32_device()
        self.port = serial.Serial(self.device, baudrate=baud, timeout=0)
        self.buffer = ""
        self.latest_sensor: dict[str, Any] = {}

    def poll(self) -> dict[str, Any]:
        waiting = self.port.in_waiting
        if waiting:
            self.buffer += self.port.read(waiting).decode("utf-8", errors="ignore")
        while "\n" in self.buffer:
            raw, self.buffer = self.buffer.split("\n", 1)
            raw = raw.strip()
            if not raw.startswith("{"):
                continue
            try:
                self.latest_sensor = json.loads(raw)
            except json.JSONDecodeError:
                continue
        return self.latest_sensor

    def send(self, command: str) -> None:
        self.port.write(f"{command}\n".encode("ascii"))
        self.port.flush()

    def close(self) -> None:
        self.send("STOP")
        self.port.close()


def choose_action(
    goal: Goal,
    target: TargetDetection | None,
    sensors: dict[str, Any],
    stop_area_ratio: float,
) -> tuple[str, str]:
    if goal.uncertainty == "high":
        return "stop", "instruction target is unsupported or unclear"
    if not sensors or "obstacle" not in sensors:
        return "stop", "ESP32 sensor status is unavailable"
    if sensors.get("sensor_fault") is True:
        return "stop", "ESP32 reports unavailable ultrasonic sensing"
    if sensors.get("obstacle") is True:
        return "stop", "ESP32 reports a front obstacle"
    if target is None:
        return "search", "target is not visible"
    if target.area_ratio >= stop_area_ratio:
        return "stop", "target occupies the goal-size image area"
    if target.center_x < 0.40:
        return "turn_left", "target is left of image centre"
    if target.center_x > 0.60:
        return "turn_right", "target is right of image centre"
    return "move_forward", "target is centred and not yet close"


def append_log(path: Path, record: dict[str, Any]) -> None:
    path.parent.mkdir(parents=True, exist_ok=True)
    with path.open("a", encoding="utf-8") as stream:
        stream.write(json.dumps(record, separators=(",", ":")) + "\n")
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

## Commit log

2026-05-23 Update new 3 approaches and remove RDK board
2026-06-12 Using one approach and docker
    [1Mount esp32.stl, 2Mount esp32.stl, Battery Mount System.stl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]
2026-06-15 update final fyp1
    [thesis_tables.xlsx]
2026-06-15 Finalize thesis project structure and documentation
    [1Mount esp32.stl, 2Mount esp32.stl, Battery Mount System.stl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]
